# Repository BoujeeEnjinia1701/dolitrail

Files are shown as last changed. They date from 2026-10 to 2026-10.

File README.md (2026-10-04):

# DoliTrail

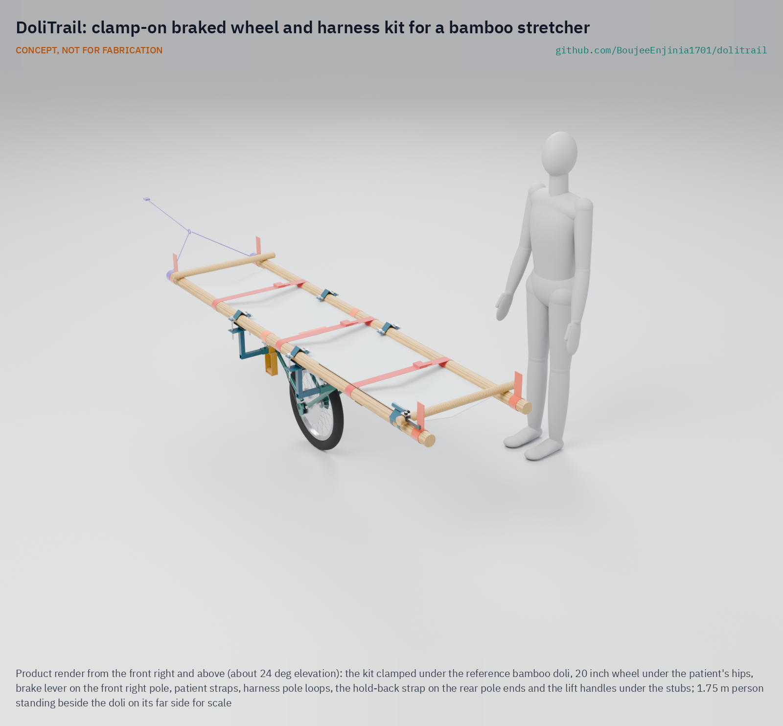
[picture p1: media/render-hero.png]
DoliTrail: clamp-on braked wheel and harness kit for a bamboo stretcher


     

**Area:** Autonomous and assisted mobility · **TRL:** 3 of 9 (proof of concept on paper; constructable design) · **Value-engineering target:** USD 1,500 (estimated cost USD 482) · **Difficulty:** 3 of 5

Adds a braked wheel and harness to the bamboo stretchers families use to carry patients to the road.

## Concept rationale

Villages without roads already have a way to move a patient: the doli, a stretcher made from bamboo poles and cloth, carried by relatives and neighbours. DoliTrail does not replace it. It adds a clamp-on wheel with a hand brake under the doli and a shoulder harness for the bearers. On level and gentle ground the wheel carries most of the weight and the bearers steer; on descents they hold speed with the brake lever; at steps, rocks and streams they lift the doli and carry it as they do today.

Keeping it as an add-on matters. Families build dolis from what is at hand, so a kit that clamps to poles of different sizes, costs little and can be carried to the village and fitted in minutes is more likely to be used than a new stretcher. The value-engineering target for the parts is USD 1,500 (the constructable design is estimated at USD 482), and the aim is a kit that a block health office or a village health committee can keep ready.

## Burning platform

The same scene repeats across India's hill and forest districts. In August 2026, ambulance staff in Mayurbhanj, Odisha, carried Sumitra Shundhi, in labour, about 7 km on a stretcher across rivers and streams because the 108 ambulance could not reach her village ([ANI, 2026](https://aninews.in/news/national/general-news/pregnant-woman-carried-7-km-on-stretcher-due-to-no-road-connectivity-in-odishas-mayurbhanj20260823102717/)). In Barwani, Madhya Pradesh, relatives carried a pregnant woman 8 km on a stretcher of cloth and bamboo sticks before an ambulance could take her a further 20 km to hospital ([The Tribune, 2021](https://www.tribuneindia.com/news/nation/madhya-pradesh-no-motorable-road-relatives-carry-pregnant-woman-on-makeshift-stretcher-for-8-km-287707)).

In Ri-Bhoi, Meghalaya, village volunteers took turns carrying a woman 36 weeks pregnant for nearly 5 km on a makeshift bamboo stretcher because no vehicle could reach the village ([The Tribune, 2022](https://www.tribuneindia.com/news/nation/pregnant-meghalaya-woman-taken-to-hospital-on-bamboo-stretcher-for-5-km-429099)). In Kondagaon, Chhattisgarh, hospital workers carried a woman 3 km on a hand-made dola over monsoon mud ([Gulf News, 2020](https://gulfnews.com/world/asia/india/india-video-of-a-pregnant-woman-who-was-taken-to-hospital-on-a-handmade-stretcher-has-gone-viral-1.1594298702634)). Each journey depends entirely on the strength of the people carrying.

## Where it could be used

### By industry

| Industry | Use |
| --- | --- |
| Public health and maternal care | Moving women in labour and patients from roadless villages to the ambulance point |
| Emergency medical services | Last-kilometre kit carried in ambulances that serve villages without roads |
| Disaster response | Casualty movement where roads are cut by floods or landslides |
| Mountain and trail rescue | Low-cost wheeled carry for volunteer teams on hill trails |
| Community health programmes | Kit held by village health committees and community health workers |

### By country or region

| Country or region | Why it matters there |
| --- | --- |
| India, Odisha | In August 2026 a woman in labour in Karanjia block, Mayurbhanj, was carried about 7 km across rivers and streams to reach an ambulance ([ANI, 2026](https://aninews.in/news/national/general-news/pregnant-woman-carried-7-km-on-stretcher-due-to-no-road-connectivity-in-odishas-mayurbhanj20260823102717/)). |
| India, Madhya Pradesh | In Barwani district, a forest village with no motorable road carried a pregnant woman 8 km on a cloth and bamboo stretcher ([The Tribune, 2021](https://www.tribuneindia.com/news/nation/madhya-pradesh-no-motorable-road-relatives-carry-pregnant-woman-on-makeshift-stretcher-for-8-km-287707)). |
| India, Meghalaya | Volunteers in Ri-Bhoi district carried a pregnant woman nearly 5 km on a bamboo stretcher over a road that had been in poor condition for years ([The Tribune, 2022](https://www.tribuneindia.com/news/nation/pregnant-meghalaya-woman-taken-to-hospital-on-bamboo-stretcher-for-5-km-429099)). |
| India, Chhattisgarh | In Kondagaon, monsoon mud cut the village off from vehicles and a woman was carried 3 km on a dola ([Gulf News, 2020](https://gulfnews.com/world/asia/india/india-video-of-a-pregnant-woman-who-was-taken-to-hospital-on-a-handmade-stretcher-has-gone-viral-1.1594298702634)). |
| India, Jammu and Kashmir | Army personnel carried a pregnant woman 6.5 km on a stretcher through heavy snow near the Line of Control in Boniyar ([The Tribune, 2022](https://www.tribuneindia.com/news/j-k/watch-army-men-carry-pregnant-woman-to-hospital-amid-heavy-snowfall-in-j-k-359452)). |

## What sparked the idea

On 23 August 2026, the 108 ambulance called for Sumitra Shundhi, in labour in Anlakanta village in Mayurbhanj, Odisha, could not reach her because there was no motorable road. The driver, the attendant and a helper carried her on the ambulance stretcher for about 7 km, crossing rivers and streams, until they reached the vehicle and took her to Karanjia hospital ([ANI, 2026](https://aninews.in/news/national/general-news/pregnant-woman-carried-7-km-on-stretcher-due-to-no-road-connectivity-in-odishas-mayurbhanj20260823102717/)). In many such villages the stretcher is a doli that families make themselves. DoliTrail asks how much of that 7 km a wheel and a brake could carry.

## Problem

In villages with no motorable road, families and health workers carry patients and women in labour for kilometres on hand-made bamboo stretchers to reach an ambulance. The whole weight rides on the bearers' shoulders, on steep, wet and uneven trails.

Full problem statement: [docs/01-problem.md](docs/01-problem.md)

## Concept

A clamp-on braked wheel and shoulder harness that fits the bamboo stretcher (doli) families already use; the bearers roll the patient along the trail, hold speed on descents with the brake lever, and lift it over steps.

Full design precis: [docs/02-concept.md](docs/02-concept.md) · Requirements: [docs/03-requirements.md](docs/03-requirements.md) · Calculations: [docs/04-calcs/01-sizing.md](docs/04-calcs/01-sizing.md) · Prototype build plan: [docs/05-build-plan.md](docs/05-build-plan.md) · Design decisions: [docs/06-design-decisions.md](docs/06-design-decisions.md)

## Key components

- Wheel and fork
- Pole clamps
- Cross frame and strap
- Brake and lever
- Bearer harnesses
- Patient straps
- Hold-back strap and lift handles
- Two carry bags and fitting card

## Building the prototype

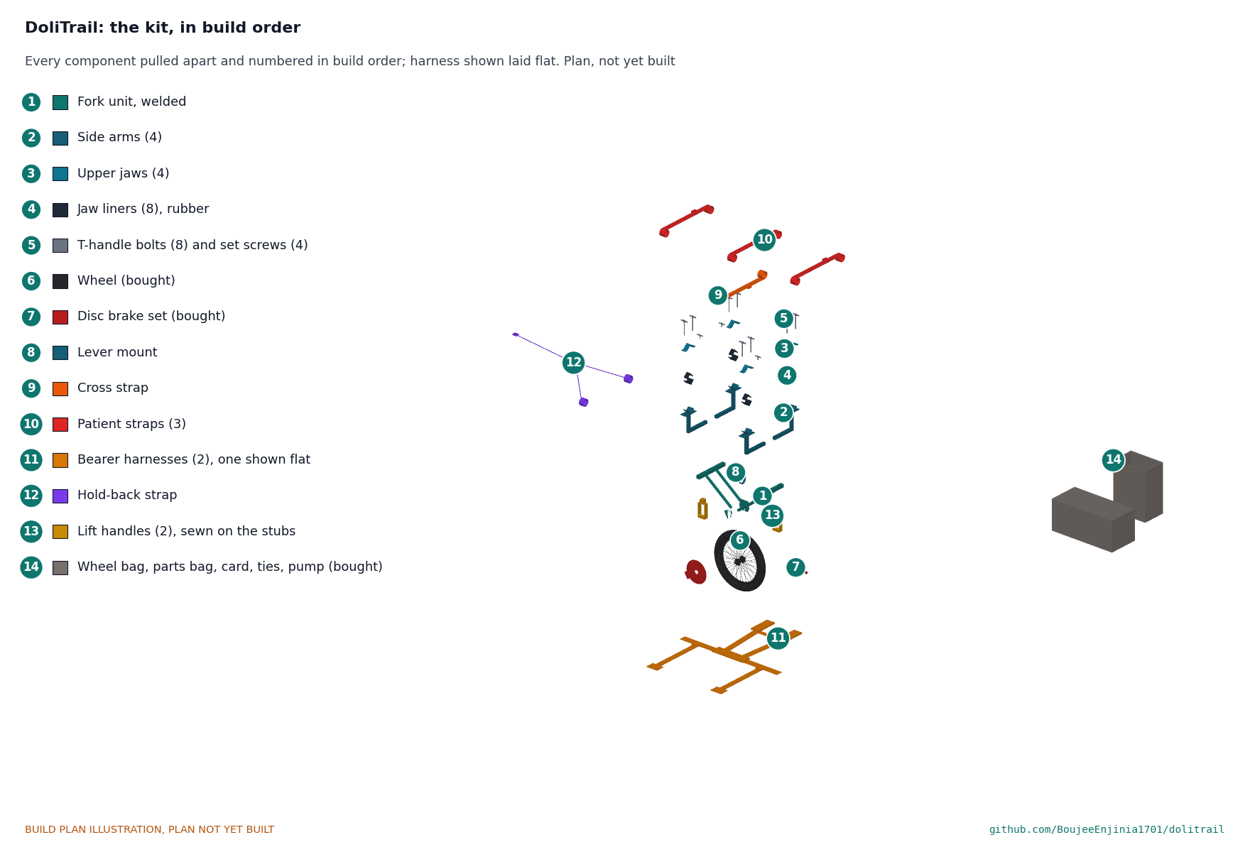
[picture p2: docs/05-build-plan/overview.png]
Every component, pulled apart and numbered in build order


The prototype build plan ([docs/05-build-plan.md](docs/05-build-plan.md)) shows how to make the kit and fit it to a doli, component by component, with a making sketch for every made part, close-ups of the joints and a picture for every assembly step. The steel parts are cut, bent, drilled and welded in a village workshop, the harnesses are sewn by a tailor, and the wheel and brake are ordinary bicycle parts. Fitting to a doli takes two people about five minutes and no tools. The plan is a plan, not yet built: the first kit carries sandbags until its proof loads and a wet ramp test have passed.

## Safety

> Safety-critical patient transport equipment. Published as an open engineering reference, never as certified medical or rescue equipment.
>
> Brake failure on a steep descent could lead to a runaway or a fall. Bearers keep hold of the poles at all times and lift and carry on slopes steeper than the tested limit.
>
> Lift and carry across streams and rivers; never roll the doli through moving water.
>
> Check clamps for grip on every fitting, since bamboo varies in size and can split.
>
> Straps must release quickly so the patient can be moved off the doli at once if needed.
>
> The doli rolls on one wheel and can tip sideways: bearers keep both hands on the poles. No person is carried until the frame, clamps and wheel have been proof-loaded (see the build plan, sections 5 and 6).
>
> This design is published as an open engineering reference. It is not certified equipment. CONCEPT, NOT FOR FABRICATION.

## Repository layout

| Folder | Contents |
| --- | --- |
| `docs/` | Problem, concept, requirements, calculations and design decisions |
| `cad/src/` | build123d Python source, the source of truth for all geometry |
| `cad/step/`, `cad/stl/` | Exported models for FreeCAD, other CAD tools and printing |
| `cad/drawings/` | 2D sketches and dimensioned drawings |
| `bom/` | Bill of materials |
| `electronics/` | KiCad schematics and PCB layouts |
| `firmware/` | Microcontroller code |
| `media/` | Renders, perspectives and photos |
| `build-log/` | Dated prototyping notes |

## Documentation

Controlled documents follow the portfolio [documentation standard](.kit/STANDARDS.md). Each carries a document ID (DLT-PRC-001 for the precis), a version and a revision history. Branded PDFs are built with `python .kit/render.py` and attached to GitHub Releases when a document is tagged, for example `DLT-PRC-001/v1.0`.

## Credits

Designed by Amish Chadha at Design Molecule Labs. See [CONTRIBUTORS.md](CONTRIBUTORS.md) for roles. To cite this design, use [CITATION.cff](CITATION.cff) (GitHub shows it as "Cite this repository").

AI assistance (Claude) was used to accelerate prototype documentation and first-pass research. Design direction and all decisions are Amish Chadha's, recorded in this repository's decision records (`docs/decisions/`).

## Licenses

- **Hardware** (CAD, drawings, BOM, electronics): [CERN-OHL-S v2](LICENSE)
- **Software** (firmware, scripts, notebooks): [MIT](LICENSE-SOFTWARE)

A project of the [Design Molecule](https://designmolecule.com) lab.

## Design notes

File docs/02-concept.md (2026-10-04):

---
doc_id: DLT-PRC-001
title: DoliTrail design precis
project: DoliTrail
doc_type: Precis
version: "0.3"
status: Draft
date: '2026-10-03'
author: Amish Chadha
license: CERN-OHL-S-2.0
revisions:
- version: "0.1"
  date: '2026-09-30'
  author: Amish Chadha
  change: Initial scaffold
- version: "0.2"
  date: '2026-10-03'
  author: Amish Chadha
  change: TRL 2 and 3 update; constructable kit (DLT-DDR-001, DLT-DDR-002), components with BOM numbers, first-order numbers, safety
- version: "0.3"
  date: '2026-10-03'
  author: Amish Chadha
  change: "Amish's round-2 decisions 6A to 9A (DLT-DDR-003): wheel proof load, hold-back strap and carry rule, two bags, lift handles and four lifters at steps"
---

# DoliTrail design precis

Adds a braked wheel and harness to the bamboo stretchers families use to carry patients to the road.

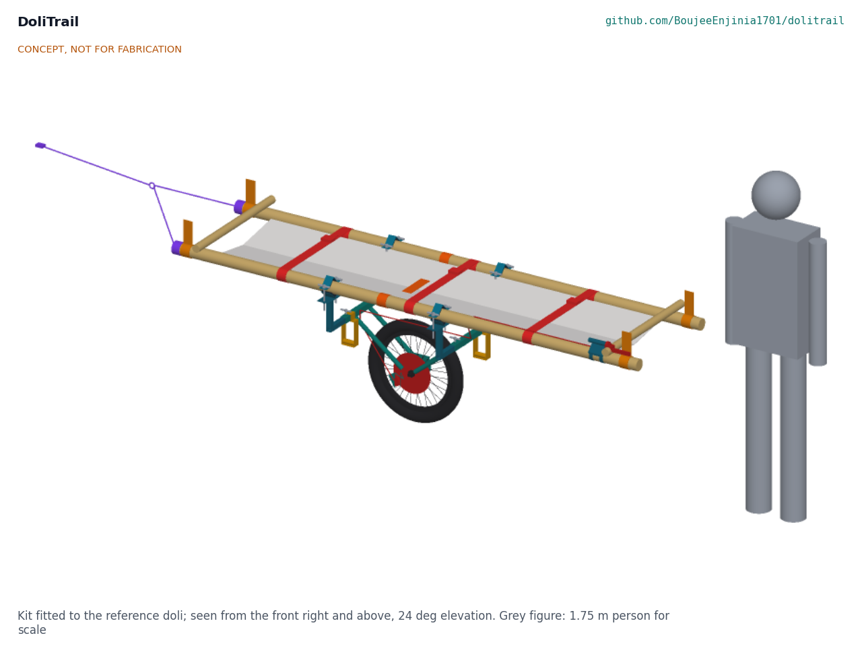
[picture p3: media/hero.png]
DoliTrail fitted to the reference doli


*Figure 1. The kit fitted to the reference doli, with a 1.75 m person for scale (concept render).*

## How it works

DoliTrail is a clamp-on kit for the doli a family has already built. A single 20 inch wheel runs under the patient's hips in a welded steel fork unit. Four side arms slide into the fork unit's two cross stubs, set to the doli's pole spacing, and each ends in a rubber-lined steel V that the bamboo pole sits in; an upper jaw and two T-handle bolts close each clamp by hand. A cross strap round both poles above the wheel keeps the bed from sagging onto the tyre. A disc brake on the wheel is worked by a lever with a parking lock, strapped to the front right pole beside the front bearer's hand. Each bearer wears a harness whose slings take the pole ends at knuckle height, so on level ground and gentle slopes the wheel carries most of the weight and the bearers balance and steer. On descents the front bearer holds speed with the brake, and the rear (uphill) bearer is tied to the rear pole ends by a hold-back strap from the hip belt; on wet clay steeper than 20 per cent the bearers lift and carry. At steps of more than about 250 mm four people lift: the two bearers and two helpers at webbing lift handles on the cross stubs. At rocks and streams the bearers lift the doli and carry it, as they do today. The kit walks in with the two bearers in two bags, and each bought wheel is proof-loaded to 285 kg before the kit is used.

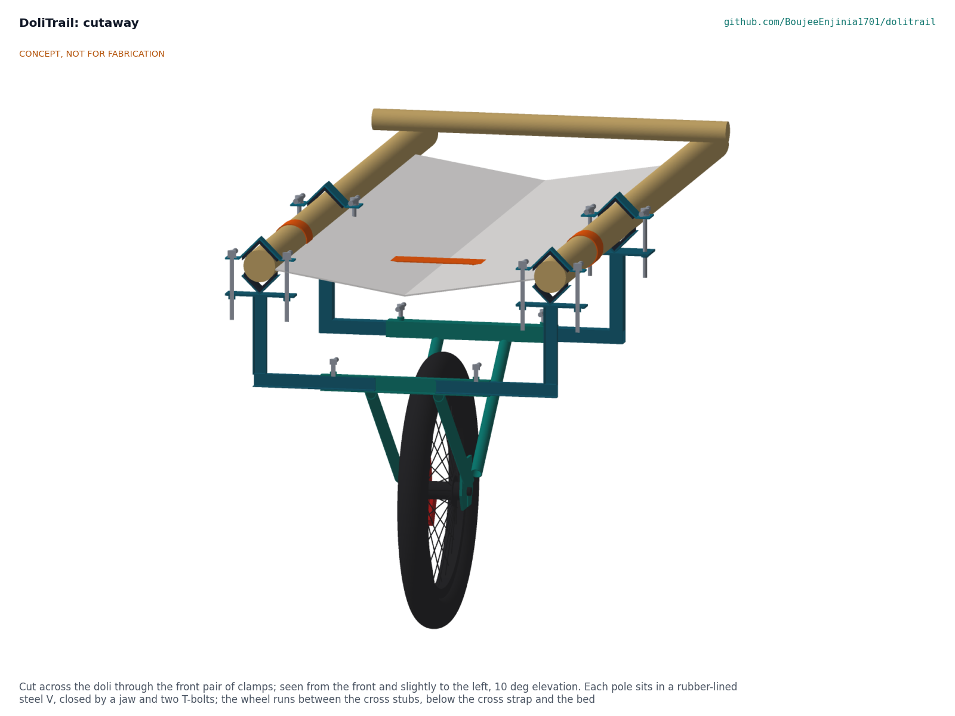
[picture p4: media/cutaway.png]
Cut across the doli through the front clamps


*Figure 2. Cut across the doli through the front pair of clamps.*

## Components

*Table 1. Components (numbers are BOM lines in `bom/bom.csv`).*

| # | Component | Role |
| --- | --- | --- |
| 1 | Fork unit | Welded steel: two 30 mm square cross stubs, four 22 mm struts, dropout plates with the brake caliper lobe |
| 2 | Side arms (4) | Square tube spigot that slides in a stub, a post and a 90 deg V saddle under the pole |
| 3 | Upper jaws (4) | Bent 3 mm steel V over the pole, with two ears for the bolts |
| 4 | Jaw liners (8) | 5 mm rubber in each saddle and jaw: grip on wet bamboo and no crushing points |
| 5 | T-handle bolts (8) and set screws (4) | Close the clamps and lock the arms by hand; no loose tools |
| 6 | Wheel | 20 inch cargo or tricycle wheel, 57-406 knobbly tyre, disc hub, solid axle |
| 7 | Disc brake set | 203 mm rotor, cable caliper with sintered pads, lever with parking lock, cable |
| 8 | Lever mount | Rubber-lined V with a 22.2 mm bar stub, strapped to the front right pole |
| 9 | Cross strap | 50 mm webbing loop round both poles above the wheel, under the bed |
| 10 | Patient straps (3) | Chest, hips and legs; cam buckles with a pull tab |
| 11 | Bearer harnesses (2) | Hip belt, padded shoulder yoke and two adjustable slings ending in pole loops |
| 12 to 15 | Wheel bag, fitting card, cable ties, pump and puncture kit | Carry, fit and keep the kit running |
| 16 | Hold-back strap | Webbing end caps over the rear pole ends, legs to a ring and a tail to the rear bearer's hip belt (decision 7A) |
| 17 | Lift handles (2) | Webbing loops sewn round the cross stubs for two helpers at steps (decision 9A) |
| 18 | Parts bag | Second bag, so each bearer carries one bag (decision 8A) |

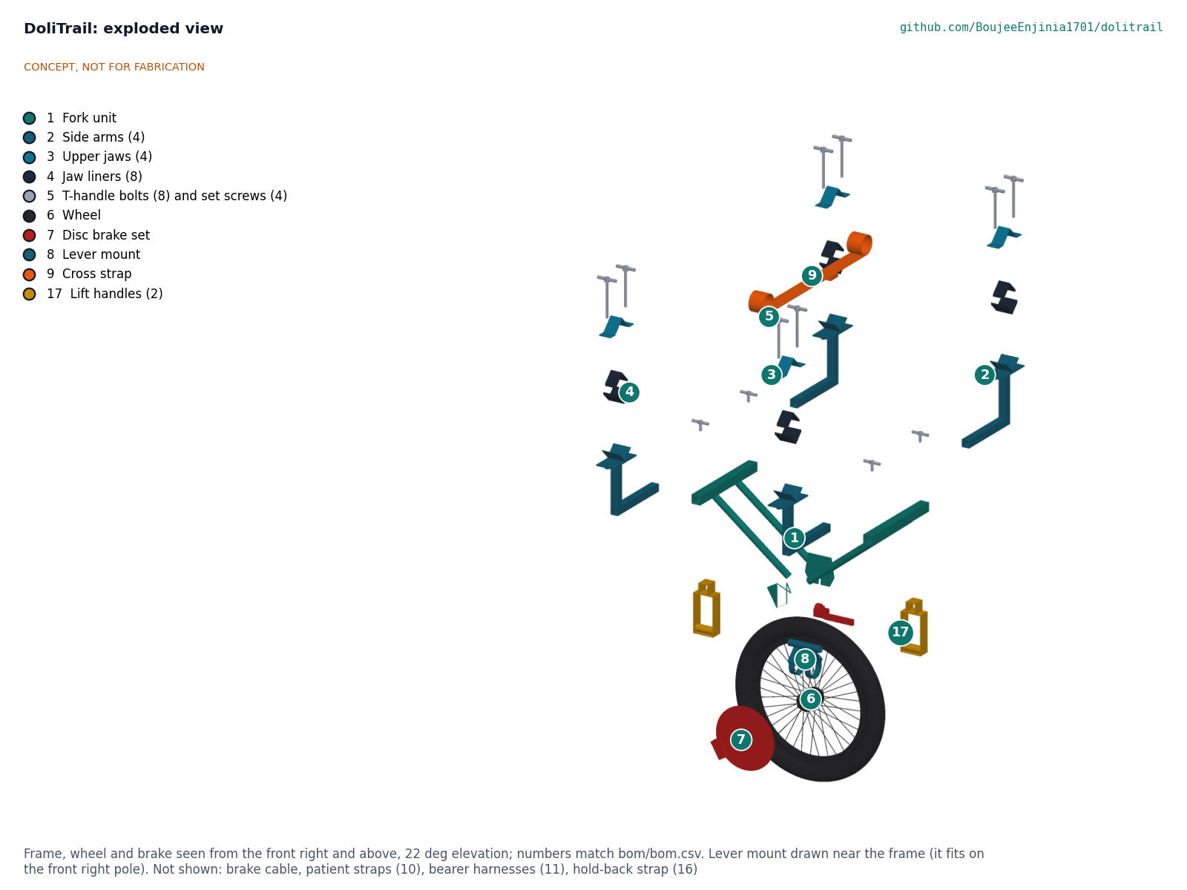
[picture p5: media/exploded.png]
Exploded view


*Figure 3. Exploded view of the frame, wheel and brake; numbers match the BOM.*

## Key design choices

- **One wheel under the hips** (DLT-DDR-001, D1). The wheel stays inside the doli's own width; a pair would need a track wider than most trails.
- **Clamp on, adjust by hand** (D2, DLT-DDR-002). Telescoping arms reach poles 450 to 600 mm apart; V saddles self-centre poles of 40 to 80 mm; T-handles mean no spanner is needed.
- **Disc brake with a parking lock** (D3). Works when wet better than a rim brake on a muddy rim; the lock holds the doli when the bearers rest on a slope.
- **Slings, not cups** (D4). A webbing pole loop fits any pole end; the scaffold's "pole-end cups" became loops.
- **Ordinary parts.** Bicycle and cycle-rickshaw parts, mild steel tube a village workshop can weld, webbing a tailor can sew.

## First-order numbers

All from DLT-CAL-001; estimates are marked.

*Table 2. Key figures.*

| Quantity | Value |
| --- | --- |
| Rolling weight: 120 kg patient, 10 kg doli, 12.5 kg fitted kit | 142.5 kg |
| Load per bearer on a level trail (estimate) | about 14 kg, against 65 kg carried by two bearers (79 per cent less) |
| Front bearer on a 30 per cent descent, brake on (estimate) | about 46 kg |
| Brake torque factor on a 30 per cent grade, wet | 1.23 |
| Tyre grip factor on a 30 per cent grade: wet ramp; wet clay | 1.44; 0.84 (lift and carry on wet clay over 20 per cent, where it is 1.37) |
| Clamp slip resistance, one pole, wet | 3.96 kN (factor 2.6 on 1.5 kN) |
| Lowest structural factor on yield at twice the rated load | 2.01 (struts); each wheel proof-loaded to 285 kg |
| Width on the reference doli | 680 mm |
| Kit in two bags; fitted | 7.2 kg and 8.3 kg; 12.5 kg |
| Lift at a 400 mm step, four people | about 36 kg each |
| Fitting time, two people (estimate) | about 4.7 min |
| Estimated parts cost | USD 482 (value-engineering target USD 1,500) |

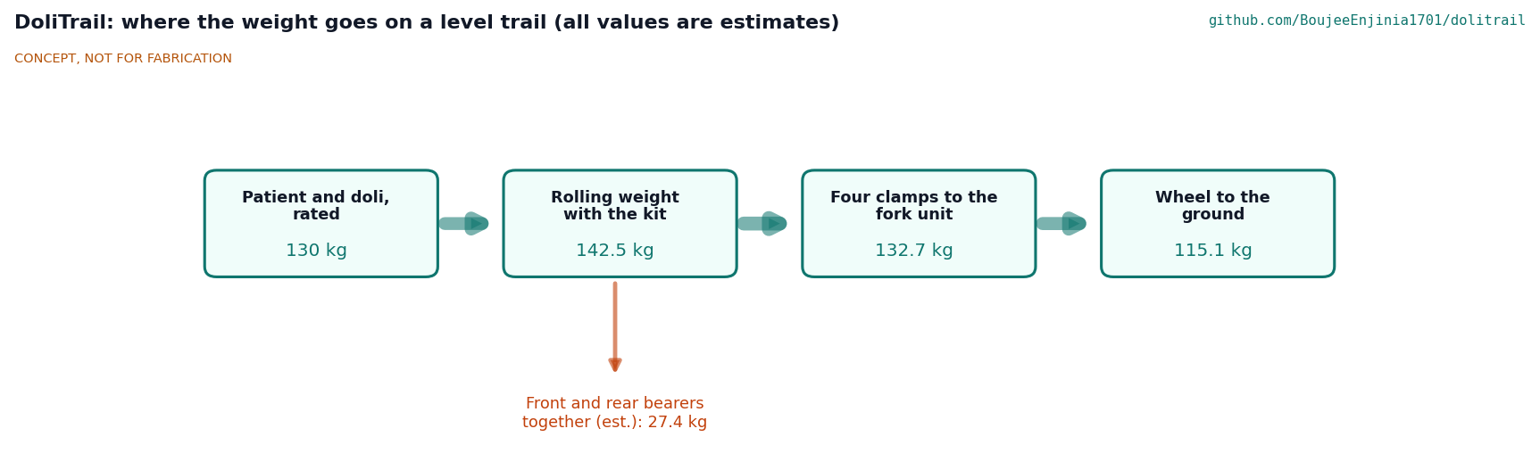
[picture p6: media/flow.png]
Where the weight goes


*Figure 4. Where the weight goes on a level trail (estimates).*

## Patent design-arounds

From the preliminary patent, trademark and prior-art screen (not legal advice), kept unchanged:

- Use DoliTrail's own clamp geometry and colours, distinct from the CMC or Ferno Mule II litter wheel. The DoliTrail clamp is a rubber-lined 90 deg V with a separate jaw and two hand bolts, on telescoping square arms; the colours are teal and blue.
- Confirm that US7922183B2 (Hill-Rom stretcher brake) has lapsed for non-payment of fees before using a similar brake arrangement. DoliTrail uses an ordinary bicycle disc brake on the wheel hub, not a stretcher-mounted brake; the check is still listed in DLT-DEC-001.

## Shared blocks

- CalRig proof-load for clamp, fork, wheel and harness load tests (TRL 4).

## Safety

> **Safety:** Safety-critical patient transport equipment. Published as an open engineering reference, never as certified medical or rescue equipment.
>
> Brake failure or tyre slip on a steep wet descent could lead to a runaway or a fall. Bearers keep hold of the poles at all times, and lift and carry on wet slopes steeper than the tested limit.
>
> The doli rolls on one wheel and can tip sideways. Both bearers steady it with both hands; on a 15 per cent side slope each hand holds about 16 kg up or down.
>
> Lift and carry across streams and rivers; never roll the doli through moving water.
>
> Check every clamp for grip on every fitting, since bamboo varies in size and can split. Tighten by hand only.
>
> Patient straps must release with one pull so the patient can be moved off the doli at once.
>
> No patient is carried until the frame, clamps and wheel have been proof-loaded (DLT-BLD-001, sections 5 and 6).

This design is published as an open engineering reference. It is not certified equipment.

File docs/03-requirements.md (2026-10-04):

---
doc_id: DLT-REQ-001
title: DoliTrail requirements
project: DoliTrail
doc_type: Requirements
version: "0.4"
status: Draft
date: '2026-10-04'
author: Amish Chadha
license: CERN-OHL-S-2.0
revisions:
- version: "0.1"
  date: '2026-09-30'
  author: Amish Chadha
  change: Initial scaffold
- version: "0.2"
  date: '2026-10-03'
  author: Amish Chadha
  change: TRL 3 status from DLT-CAL-001 on the constructable design; R10 and R11 added (DLT-DDR-001); targets R1 to R9 unchanged
- version: "0.3"
  date: '2026-10-03'
  author: Amish Chadha
  change: "Status of R3, R5, R7, R8 and R9 after Amish's round-2 decisions 6A to 9A (DLT-DDR-003); targets unchanged; wording of R7 and R8 posed to Amish (DLT-DEC-001, O5)"
- version: "0.4"
  date: '2026-10-04'
  author: Amish Chadha
  change: "R7 and R8 restated by Amish's round-3 decision 1A (DLT-DDR-004): R7 as two bags of 10 kg or less, one per bearer; R8 as four people at steps, two at the lift handles; both met as designed"
---

# DoliTrail requirements

Requirements for the kit fitted to the reference doli (two 60 mm bamboo poles, 2.55 m long, at 550 mm centres) carrying the rated patient. R1 to R9 keep the targets set at TRL 1; R10 and R11 were added at TRL 2 (DLT-DDR-001). Status is the paper result at TRL 3 from DLT-CAL-001; every requirement is verified by test at TRL 4. Requirements not met or at risk are posed to Amish as decisions in `docs/REVIEW.md` and `docs/06-design-decisions.md`.

On 2026-10-03 Amish decided the four requirement decisions on R3, R5, R7 and R8 as recommended: "i agree with all the 46 recommendations you provided. please proceed." (decisions 6A to 9A, DLT-DDR-003). The targets are unchanged. R7 and R8 are met only in the way those decisions set out (two bags; four people at steps). On 2026-10-04 Amish decided option 1A on their wording: "For round 3, I agree with all your proposed recommendations". R7 is now restated as "two bags of 10 kg or less, one per bearer" and R8 as "four people at steps, two at the lift handles" (DLT-DDR-004). Both are met as designed.

*Table 1. Requirements.*

| ID | Requirement | Target | Verification (TRL 3 or later) | TRL 3 status |
| --- | --- | --- | --- | --- |
| R1 | Fits real dolis | Clamps grip poles of 40 to 80 mm diameter and hold without slipping under a 1.5 kN load (target) | Fit trials on 10 field-made dolis and CalRig pull tests | Met on paper: the clamps close on 40 and 80 mm poles in the model; two clamps on one pole resist 3.96 kN wet (factor 2.6); bamboo crushing factor 2.0 to confirm on real poles |
| R2 | Quick to fit | Two people fit the kit to a doli in under 5 minutes | Timed trials using only the fitting card | Met on paper (estimate): about 4.7 min, with the wheel carried fitted in the fork unit |
| R3 | Carry load | Rated for a 120 kg (265 lb) patient plus doli, with a 2 to 1 safety margin on the wheel, fork and clamps | CalRig proof-load test | Met on paper for the fork, arms and clamps (lowest factor 2.01 on yield at twice the rated load). The wheel and tyre are not catalogue-rated for twice the wheel load, so each bought wheel is proof-loaded to 285 kg before use, with the heavier tricycle wheel if it fails (decision 6A) |
| R4 | Reduce bearer load | Average vertical load per bearer reduced by at least 60 per cent on level trail compared with carrying | Load cells in the harness cups during trail trials | Met on paper (estimate): 79 per cent (about 14 kg per bearer against 65 kg) |
| R5 | Brake holds on descents | Holds the rated load stationary on a 30 per cent grade, wet | Wet ramp test | Met on paper on the wet test ramp: brake factor 1.23, tyre grip factor 1.44. On wet clay the grip factor on 30 per cent is 0.84, so the bearers lift and carry on wet clay steeper than 20 per cent (grip factor 1.37 there), and a hold-back strap ties the uphill bearer to the rear pole ends (decision 7A) |
| R6 | Narrow trails | Overall width with wheel at or below 700 mm (28 in) | Measure; walk a marked 0.8 m trail course | Met on the reference doli: 680 mm; any doli with poles at more than 570 mm centres is wider than 700 mm by itself |
| R7 | Portable | Two bags of 10 kg (22 lb) or less, one per bearer | Weigh; timed carry of the bagged kit | Met as designed (decisions 8A and 1A): two bags of 7.2 and 8.3 kg, one carried by each bearer; the whole kit is 15.5 kg |
| R8 | Lift over obstacles | Four people at steps, two at the lift handles: the fitted doli goes over a 400 mm step without removing the wheel | Obstacle course trial | Met as designed (decisions 9A and 1A): the two bearers and two helpers at lift handles on the cross stubs, about 36 kg each. Two bearers alone would each lift about 71 kg to chest height, so the drill rules that out |
| R9 | Low cost | Parts cost at or below $1,500 USD for the kit | Costed bill of materials | Value-engineering target: USD 1,500. Estimated cost of the constructable design: USD 482 (USD 1,018 under the target) |
| R10 | Patient release | Each patient strap frees with one pull of one hand in 3 s or less | Timed trial, gloved hand | Met by design: cam buckles with a pull tab |
| R11 | Brake within reach | The front bearer works the brake and its parking lock without letting go of the poles | Trial with bearers of 1.5 to 1.8 m | Met on paper: lever on the front right pole about 100 to 150 mm behind the pole loop |

## Assumptions

- Rated load: a 120 kg patient on a 10 kg doli; with the 12.5 kg fitted kit the rolling weight is 142.5 kg (DLT-CAL-001, A1).
- The wheel is placed under the patient's hips to within 100 mm; bearers steady the doli with about 5 per cent of the rolling weight each.
- Typical routes roll on level ground and moderate grades; bearers lift and carry at rocks, water and wet clay steeper than 20 per cent, and four people lift at steps (decisions 7A and 9A).
- Bamboo poles carry the patient through four clamps at about 600 mm spacing near mid-span.
- Ambulance services and health committees would keep and maintain kits.

> **Safety:** These requirements describe equipment that carries a person over dangerous ground. A paper result is not a test. No patient is carried until the TRL 4 proof loads and first checks in DLT-BLD-001 pass.

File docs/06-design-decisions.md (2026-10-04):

---
doc_id: DLT-DEC-001
title: DoliTrail design decisions register
project: DoliTrail
doc_type: Design decisions register
version: "0.3"
status: Draft
date: '2026-10-04'
author: Amish Chadha
license: CERN-OHL-S-2.0
revisions:
- version: "0.1"
  date: '2026-10-03'
  author: Amish Chadha
  change: Register opened; design decisions made under Amish's 2026-10-03 pre-approvals; four requirement decisions proposed, awaiting Amish
- version: "0.2"
  date: '2026-10-03'
  author: Amish Chadha
  change: "O1 to O4 decided by Amish (6A to 9A, DLT-DDR-003) and moved to Decisions made; new O5 on the wording of R7 and R8, proposed, awaiting Amish"
- version: "0.3"
  date: '2026-10-04'
  author: Amish Chadha
  change: "O5 decided by Amish (round-3 decision 1A, DLT-DDR-004) and moved to Decisions made; no open decisions"
---

# DoliTrail design decisions register

Every design decision still to be made, and every decision made, in one place. Each decision is argued in full in its decision record under `docs/decisions/` or in `docs/REVIEW.md`; this register is the index Amish works from. The build plan (`docs/05-build-plan.md`) describes the design as it stands and does not list decisions.

> **Safety:** Several entries set safety limits (one wheel steadied with both hands, a parking lock on every kit, a solid axle, hand-tight clamps, sandbags before people, lift and carry on wet clay). Each takes the conservative option and names the evidence that would relax it. DoliTrail is not certified medical or rescue equipment.

## Open decisions

None. O1 to O4 were decided on 2026-10-03 and O5 (the wording of R7 and R8) on 2026-10-04; all are under Decisions made.

## To confirm when parts are bought

These are facts that can only be settled with real parts, real dolis or the first partner. None changes a decision; each may change a size or a limit.

*Table 2. Items to confirm.*

| # | What to confirm | Why it matters | Source |
| --- | --- | --- | --- |
| 1 | Seller's ratings of the bought wheel (200 kg assumed) and tyre (150 kg); each wheel is proof-loaded to 285 kg before use (decision 6A) | R3 | DLT-CAL-001, A10 |
| 2 | Brake clamp force at about 150 N hand pull with the lock set (2.0 kN per pad assumed) and wet pad friction (0.35) | R5 brake factor | DLT-CAL-001, A5 |
| 3 | Diametral crushing of local bamboo poles of 40 to 80 mm in the V jaws (4.0 kN for 40 mm length assumed) | R1 crushing factor, the hand-tight rule | DLT-CAL-001, A7 |
| 4 | Rubber on wet bamboo friction (0.35 assumed) | R1 slip factor | DLT-CAL-001, A6 |
| 5 | Tyre grip on the partner's trails, wet (0.35 assumed), and whether the 20 per cent carry limit on wet clay suits them | R5, decision 7A | DLT-CAL-001, A4, A13 |
| 6 | How real dolis' beds are fixed to the poles; whether the lashing can be slid aside at the clamp points, and what to do with sewn sleeves | Clamp position; fitting time | DLT-DDR-002, A3 |
| 7 | Pole spacing, diameter and length of dolis in the partner's villages | Arm range and width (R6) | DLT-DDR-001, D6 |
| 8 | Masses of the bought wheel, brake, harness webbing and bag | R7 | DLT-CAL-001, A12 |
| 9 | That US7922183B2 (Hill-Rom stretcher brake) has lapsed, before any public claim about the brake | Design-around | DLT-PRC-001 |
| 10 | Breaking strength of the 25 and 50 mm webbing bought for the hold-back strap and lift handles (5 and 10 kN assumed), and that the end caps stay on poles of 40 to 80 mm under a backward pull | Decisions 7A and 9A | DLT-CAL-001, A14 |

## Value engineering

Value-engineering target: USD 1,500 (a hypothetical control target, not a limit). Estimated cost of the constructable design: USD 482 (USD 1,018 under the target). Main cost drivers and savings worth trying:

- The largest lines are the two harnesses (USD 70), the fork unit (USD 62), the four side arms (USD 60), the wheel (USD 55) and the brake set (USD 45).
- Savings worth trying: cycle-rickshaw workshops already weld similar frames and could make the fork unit and arms together in a batch (perhaps USD 30 a kit); harnesses from used truck seat-belt webbing (about USD 25); a secondhand cargo wheel inspected and proof-loaded (about USD 25).
- Decisions 6A to 9A added USD 27 (hold-back strap USD 6, two lift handles USD 6, parts bag USD 15). If a bought wheel fails its proof load, the heavier tricycle wheel adds about USD 30.

## Decisions made

*Table 3. Decisions made.*

| Date | Decision | Decided by | Record |
| --- | --- | --- | --- |
| 2026-10-03 | TRL 2 review items D1 to D9: one wheel under the hips; rubber-lined V clamps on telescoping arms with hand bolts; cable disc brake with a parking lock on every kit; pole loops on slings; 20 inch cargo wheel with a solid axle; rated patient 120 kg on a 10 kg reference doli; first-trial kits kept in the ambulance; first co-design candidates (a district 108 ambulance operator in Mayurbhanj, a maternal health NGO in the same block, a volunteer mountain rescue group; none approached yet); R10 and R11 added, R1 to R9 targets unchanged; pitch, design-arounds and budget unchanged | Amish, pre-approval of 2026-10-03: "start with the first 14 repos from the list of 29 projects. I pre-approve the batch runs along with any recommendations you come up with. I also accept any cost overruns or variations from the assumed scope cost." and "Proceed with the remaining 15 scaffolds" | DLT-DDR-001 |
| 2026-10-03 | Design for construction, changes C1 to C11: welded fork unit with cross stubs and struts; telescoping side arms with V saddles; T-handle bolts and set screws; cross strap; caliper lobe on the dropout plate; lever mount; pole loops; solid axle in open slots; clamps on bare pole; wheel bag; pump and ties | Amish, same pre-approvals | DLT-DDR-002 |
| 2026-10-03 | Assumptions A1 to A5: sound poles only; clamps hand tight, never with a bar (conservative; relaxed only by crush tests on local bamboo); sewn bed sleeves not fitted until the partner trial decides; bought ratings confirmed; jig-welded, inspected frame | Amish, same pre-approvals | DLT-DDR-002 |
| 2026-10-03 | Sandbags before people: no person on the doli before the frame and wheel proof loads and the wet ramp test pass; the first person carried is a healthy volunteer (conservative; a gate, not relaxed) | Amish, same pre-approvals | DLT-BLD-001, sections 5 and 6 |
| 2026-10-03 | O1, R3 (6A): keep the 20 inch cargo wheel; proof-load each bought wheel to 285 kg before use; heavier tricycle wheel and 20 x 2.4 cargo tyre only if it fails | Amish: "i agree with all the 46 recommendations you provided. please proceed." | DLT-DDR-003 |
| 2026-10-03 | O2, R5 (7A): hold-back strap from the uphill bearer's hip belt to the rear pole ends; lift and carry on wet clay steeper than 20 per cent | Amish, same words | DLT-DDR-003 |
| 2026-10-03 | O3, R7 (8A): the kit in two bags, about 7 and 8 kg, one per bearer | Amish, same words | DLT-DDR-003 |
| 2026-10-03 | O4, R8 (9A): four people lift at steps, two at lift handles added to the frame, about 36 kg each | Amish, same words | DLT-DDR-003 |
| 2026-10-03 | Appearance model departures: bamboo and cloth colours for the family's doli, a 1.75 m mannequin standing beside the doli on its far side, and a repeated front right clamp for the detail view, drawn for the renders only | Amish, same pre-approvals | docs/REVIEW.md, TRL 3 section |
| 2026-10-04 | O5, R7 and R8 (1A): R7 restated as "two bags of 10 kg or less, one per bearer"; R8 restated as "four people at steps, two at the lift handles"; both met as designed | Amish: "For round 3, I agree with all your proposed recommendations" | DLT-DDR-004 |

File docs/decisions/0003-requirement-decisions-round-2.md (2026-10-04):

---
doc_id: DLT-DDR-003
title: DoliTrail requirement decisions on R3, R5, R7 and R8
project: DoliTrail
doc_type: Design decision record
version: "0.1"
status: Draft
date: '2026-10-03'
author: Amish Chadha
license: CERN-OHL-S-2.0
revisions:
- version: "0.1"
  date: '2026-10-03'
  author: Amish Chadha
  change: Amish's round-2 decisions 6A, 7A, 8A and 9A recorded and carried into the design
---

# 0003: Requirement decisions on R3, R5, R7 and R8

- **Date:** 2026-10-03
- **Status:** accepted. Decided by Amish on 2026-10-03: "i agree with all the 46 recommendations you provided. please proceed." For DoliTrail this accepts the recommendations on open decisions O1 to O4 of DLT-DEC-001 (portfolio items 6A, 7A, 8A and 9A).

## Context

The TRL 3 calculations (DLT-CAL-001 v0.1) left four requirements short or at risk: the wheel and tyre are not catalogue-rated for twice the wheel load (R3); on wet clay the tyre slides before the brake slips (R5); the kit weighed 14.8 kg in one bag (R7); and two bearers would each lift about 71 kg to chest height to clear a 400 mm step (R8). Each was posed with options in `docs/REVIEW.md` (D-A1 to D-A4).

## Options considered

The options are set out in full in `docs/REVIEW.md`, TRL 3 section, "Decisions for Amish". In short: R3 by proof load, a heavier tricycle wheel or a scooter wheel; R5 by a hold-back strap and a carry rule, a drag claw or a mud tyre; R7 by two bags, lighter parts or an aluminium frame; R8 by four lifters with handles or shoulder yokes.

## Decision

| Item | Requirement | Decision (option A in each case) |
| --- | --- | --- |
| 6A | R3 | Keep the 20 inch cargo wheel. Proof-load each bought wheel, with its tyre at full pressure, to 285 kg for 10 minutes before the kit is used; move to the heavier 20 inch tricycle wheel and 20 x 2.4 cargo tyre only if it fails. |
| 7A | R5 | Add a hold-back strap from the uphill (rear) bearer's hip belt to the rear pole ends, and the rule to lift and carry on wet clay steeper than 20 per cent. |
| 8A | R7 | Split the kit into two bags, one carried by each bearer: about 7 and 8 kg. |
| 9A | R8 | Four people lift at steps: the two bearers at the pole ends and two helpers at two lift handles added to the frame, about 36 kg each. |

## Consequences

Carried out on 2026-10-03:

- **Model** (`cad/src/model.py`): hold-back strap (BOM line 16): two closed webbing end caps 40 mm deep over the rear pole ends, so the pull bears on the end of each pole, two 25 mm legs to a 40 mm steel ring and a 600 mm tail with a cam buckle to the rear bearer's hip belt. Lift handles (line 17): a 40 mm webbing band sewn shut round each cross stub, 100 mm off centre (front stub left, rear stub right, so the helpers stand on opposite sides), with a 130 mm hand loop and a foam grip. Sixteen new constructability checks (91 of 91 pass): caps on the pole ends and 5 mm clear of the harness loops; legs, ring and tail clear of the poles, cross sticks and harness loops; handles on their stubs, clear of the arms, set screws and brake, 69 mm clear of the tyre, 162 mm of hand room under the poles and bed, 358 mm above the ground.
- **Bags:** the wheel bag (line 12) carries the fork unit with the wheel, brake, lift handles and pump kit (7.2 kg); a new parts bag (line 18) carries the arms, jaws, bolts, lever mount, straps, harnesses and hold-back strap (8.3 kg).
- **Results** (DLT-CAL-001 v0.2): R3 frame factor 2.01, wheel proof load 285 kg [S12]; R5 brake 1.23, wet ramp grip 1.44, wet clay grip 1.37 at the 20 per cent carry limit [B9], hold-back pull 65 N on 30 per cent wet clay met by surprise [B10]; R7 two bags of 7.2 and 8.3 kg [K13], [K14], 15.5 kg in all; R8 about 36 kg each with four people [H4], 350 N on each handle [H5].
- **Cost and mass:** USD 27 more (hold-back strap USD 6, two lift handles USD 6, parts bag USD 15). Value-engineering target: USD 1,500. Estimated cost of the constructable design: USD 482 (USD 1,018 under the target). Fitted kit 12.5 kg; rolling weight 142.5 kg.
- **New question:** R7 and R8 are met only in the way these decisions set out (per bag; with four people), while their wording still says one person and two bearers. Whether to restate them is posed to Amish as O5 in DLT-DEC-001.

> **Safety:** The hold-back strap helps, it does not replace the carry rule: on wet clay steeper than 20 per cent the bearers lift and carry. The wheel proof load is done with sandbags under safety stop S3 before any person is carried.

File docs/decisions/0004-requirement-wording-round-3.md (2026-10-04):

---
doc_id: DLT-DDR-004
title: DoliTrail wording of R7 and R8
project: DoliTrail
doc_type: Design decision record
version: "0.1"
status: Draft
date: '2026-10-04'
author: Amish Chadha
license: CERN-OHL-S-2.0
revisions:
- version: "0.1"
  date: '2026-10-04'
  author: Amish Chadha
  change: Amish's round-3 decision 1A recorded; R7 and R8 restated
---

# 0004: Wording of R7 and R8

- **Date:** 2026-10-04
- **Status:** accepted. Decided by Amish on 2026-10-04: "For round 3, I agree with all your proposed recommendations". For DoliTrail this accepts option A of open decision O5 in DLT-DEC-001 (portfolio item 1A).

## Context

Decisions 8A and 9A (DLT-DDR-003) met R7 and R8 with two bags and four people, while the requirement text still said one person carries the kit and two bearers lift at steps.

## Options considered

A: restate R7 and R8 to match the design. B: keep the wording and report both as met only per bag and with four people. Recommendation was A.

## Decision

- R7 is restated as "two bags of 10 kg or less, one per bearer". Result: bags of 7.2 and 8.3 kg. Met as designed.
- R8 is restated as "four people at steps, two at the lift handles". Result: about 36 kg each. Met as designed.

## Consequences

Requirements text, calculation note wording and registers only. No geometry, bill of materials or cost change. Value-engineering target: USD 1,500. Estimated cost of the constructable design: USD 482 (USD 1,018 under the target).

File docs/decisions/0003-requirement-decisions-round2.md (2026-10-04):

---
doc_id: DLT-DDR-003
title: DoliTrail requirement decisions, round 2
project: DoliTrail
doc_type: Design decision record
version: "0.1"
status: Draft
date: '2026-10-03'
author: Amish Chadha
license: CERN-OHL-S-2.0
revisions:
- version: "0.1"
  date: '2026-10-03'
  author: Amish Chadha
  change: Decisions O1 to O4 on R3, R5, R7 and R8, decided by Amish on 2026-10-03 and carried into the model, calculations, BOM and build plan
---

# 0003: Requirement decisions, round 2

- **Date:** 2026-10-03
- **Status:** Decided. Decided by Amish Chadha, 2026-10-03: "i approve all of the 47 recommendations provided by you. Execute them." Each decision below is the recommendation as worded in `docs/06-design-decisions.md` (DLT-DEC-001 v0.1), including its conditions.

> **Safety:** Three of these decisions (O1, O2 and O4) concern carrying a person. Each is the conservative option and puts a person, a proof load or a rule between the patient and the shortfall. None of them is a test: no person is carried until the TRL 4 proof loads, including the 285 kg static proof load of the wheel and tyre, and the wet ramp test have passed (DLT-BLD-001, sections 5 and 6). DoliTrail is not certified medical or rescue equipment.

## Context

DLT-CAL-001 v0.1 left R3 (carry load) and R5 (brake holds on descents) at risk, and R7 (portable) and R8 (lift over obstacles) not met. Each was posed as Proposed, awaiting Amish, with options and a recommendation.

## Decision

Table 1. Decisions

| # | Requirement | Option chosen | Effect (DLT-CAL-001 v0.2) | Condition |
| --- | --- | --- | --- | --- |
| O1 | R3, wheel and tyre margin | **A:** keep the 20 inch cargo wheel and prove it with a 285 kg static proof load before any person is carried | No change to the wheel, cost or mass. R3 met if the proof load holds; until then the wheel (0.70) and tyre (0.53 of twice the wheel load on their ratings) are unproven. The proof load is a TRL 4 step, written into the build plan's first checks and safety stops S4 and S5 | Moving to B, a heavier 20 inch tricycle wheel and a 20 x 2.4 cargo tyre (about USD 30 more, 0.6 kg heavier), only if the proof load fails; the proof load is then repeated |
| O2 | R5, grip on a wet descent | **A:** a hold-back strap from the rear bearer's hip belt to the rear pole ends, plus a rule to lift and carry on wet clay steeper than 20 per cent | BOM line 17 (USD 6, 0.2 kg) and a D-ring on the rear bearer's hip belt; hold-back loops on the rear pole ends in the model. The rear bearer holds the shortfall of about 7 kg-force on wet clay at 30 per cent; worst case 402 N if the wheel slides fully, a factor of 12 on the webbing's assumed 5 kN. Tyre grip factor at 20 per cent on wet clay is 1.37. R5 met with the bearer's help, not by the kit alone | The rule is on the fitting card and in safety stop S5 |
| O3 | R7, kit mass | **A:** two bags carried by the two bearers | BOM line 12 becomes two bags (USD 15 more, 0.3 kg). Kit 15.5 kg (with the O2 and O4 parts) in bags of about 6.9 kg and 8.7 kg, each within R7, but not one load for one person | None |
| O4 | R8, lifting over a 400 mm step | **A:** four bearers at steps over about 250 mm, the two helpers lifting at webbing handles on the cross stubs | BOM line 16 (two handles, USD 6, 0.2 kg); handles wrapped round the cross stubs in the model, checked clear of the struts, set screws, wheel and brake. About 36 kg per person at a 400 mm step. R8 met with four people, not two | The rule is on the fitting card and in safety stop S5 |

## Consequences

- Requirement status (DLT-REQ-001 v0.3): R3 at risk to met if the proof load holds; R5 at risk to met with the bearer's help; R7 not met to each load met, not one load for one person; R8 not met to met with four people. No requirement was restated.
- Estimated cost: USD 455 to USD 482 against the USD 1,500 value-engineering target (USD 1,018 under). Kit 14.8 to 15.5 kg; fitted 12.3 to 12.5 kg; rolling weight 142.5 kg, so twice the wheel load is still 285 kg.
- Model: 83 of 83 constructability checks pass (75 before; eight new checks for the lift handles and hold-back loops). STEP and STL, general arrangement DLT-DWG-001 Rev P3, the concept media with blueprint DLT-DWG-010 Rev P2, the build plan pictures (two new joint close-ups) and `media/model.glb` are regenerated.
- New open decision O5 in `docs/06-design-decisions.md`: below the 250 mm threshold two bearers still lift about 71 kg each, by up to 300 mm.

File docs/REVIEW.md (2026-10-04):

# Review note: DoliTrail

## Session 2026-09-30: scaffolded

### What was done

- Repository created from kit 1.6.0 at TRL 1, target TRL 2.
- `docs/01-problem.md` (DLT-PRB-001 v0.1): problem with cited evidence, users, environment, constraints, prior work, open questions.
- `docs/02-concept.md` (DLT-PRC-001 v0.1): how it works, components, patent design-arounds, shared blocks, safety.
- `docs/03-requirements.md` (DLT-REQ-001 v0.1): 9 proposed requirements.
- `README.md` with concept rationale, burning platform, where it could be used, and what sparked the idea.

### Next

- Run `/populate` to bring the repo to a strong TRL 2 with concept media.

## Session 2026-10-03: TRL 2 (populate)

Run as the first half of `/to-trl3` under Amish's pre-approval of 2026-10-03: "start with the first 14 repos from the list of 29 projects. I pre-approve the batch runs along with any recommendations you come up with. I also accept any cost overruns or variations from the assumed scope cost." and his instruction of the same day for batch 2: "Proceed with the remaining 15 scaffolds". Kit 1.7.0 installed.

### What was done

- `docs/01-problem.md` (DLT-PRB-001 v0.2): constraints restated (value-engineering target, clamps on bare pole), open questions settled, first co-design candidates, safety section.
- `docs/02-concept.md` (DLT-PRC-001 v0.2): how it works, components with BOM numbers, key design choices, first-order numbers, design-arounds kept, safety.
- `docs/03-requirements.md` (DLT-REQ-001 v0.2): R1 to R9 with targets unchanged; R10 and R11 added; TRL 3 status.
- Concept media from `cad/src/concept_media.py`: `media/hero.png` (1.75 m person), `media/cutaway.png` (cut through the front clamps), `media/exploded.png` (BOM callouts), `media/flow.png` (where the weight goes, estimates), `media/concept-blueprint.png`, `.pdf` and `.svg` (DLT-DWG-010), `media/model.glb` (1.7 MB, coarse tessellation) and `media/viewer.html`.
- `bom/bom.csv`: 15 priced lines.

### Results

- One wheel under the patient's hips keeps the kit inside the doli's own width; the clamps reach every pole size in the problem statement.

### Requirements not met

- R3, R5, R7 and R8 (see TRL 3).

### Decisions made under the pre-approval

DLT-DDR-001, items D1 to D9: one wheel; V clamps on telescoping arms with hand bolts; cable disc brake with a parking lock; pole loops on slings; 20 inch cargo wheel with a solid axle; rated load and reference doli; first-trial kits in the ambulance; first co-design candidates (not approached); R10 and R11 added.

### Safety concerns

- The doli rolls on one wheel and can tip sideways; bearers keep both hands on the poles.

## Session 2026-10-03: TRL 3 (advance and build plan)

Run as the second half of `/to-trl3` under the same pre-approvals, which count as the TRL 2 approval. Not committed or pushed (batch run).

### What was done

- `cad/src/model.py`: parametric build123d model of the kit on the reference doli (two 60 mm bamboo poles at 550 mm centres); 75 of 75 constructability checks pass (wheel in the fork with 15 mm mud clearance, axle nuts on the plates, caliper on its lobe and clear of spokes, arms in the stubs, liners on the pole, the clamp closing on 40 and 80 mm poles, bolts clear of the pole, strap and bed 100 mm or more above the tyre, 150 mm ground clearance, width). Exports `cad/step/dolitrail-assembly.step`, `dolitrail-kit.step`, `reference-doli-context.step`, the fork unit, side arm, upper jaw and lever mount, and STL of the arm, jaw, liners and lever mount.
- `docs/04-calcs/01-sizing.md` (DLT-CAL-001 v0.1) with `docs/04-calcs/sizing.py` and `results.csv`.
- `cad/src/sheets.py`: general arrangement `cad/drawings/DLT-DWG-001` (SVG, PDF, PNG) at Rev P2, with section A-A at 1:10.
- `cad/src/build_plan_media.py`: `docs/05-build-plan/overview.png`, 6 making sketches `cad/drawings/DLT-DWG-101` to `106`, 8 joint close-ups and 9 step pictures.
- `docs/05-build-plan.md` (DLT-BLD-001 v0.1), `docs/06-design-decisions.md` (DLT-DEC-001 v0.1), `docs/decisions/0001-trl2-review-decisions.md` (DLT-DDR-001) and `docs/decisions/0002-design-for-construction.md` (DLT-DDR-002).
- `cad/src/product_model.py` (appearance model) and render scenes exported with `.kit/export_views.py` to `/home/claude/renders/dolitrail` for hero, exploded and detail views; photoreal renders and cards are made on Amish's Mac.
- `project.yaml`: trl 3, trl_target 3, `design_state: constructable`, evidence listed; `budget_usd` unchanged. README leads with `media/render-hero.png` and has a "Building the prototype" section.

### Results

- Rolling weight 142 kg (120 kg patient, 10 kg doli, 12.3 kg fitted kit).
- Level trail: about 14 kg per bearer against 65 kg carried by two bearers, 79 per cent less (estimate). On a 30 per cent descent with the brake on, the front bearer holds about 46 kg (estimate).
- Brake factor 1.23 on a wet 30 per cent grade; tyre grip factor 1.44 on a wet ramp and 0.84 on wet clay.
- Clamps: 3.96 kN slip resistance per pole, wet (factor 2.6); bamboo crushing factor 2.0 to confirm.
- Lowest structural factor on yield at twice the rated load: 2.02 (struts).
- Width 680 mm on the reference doli; fitting about 4.7 min (estimate); kit 14.8 kg in the bag.
- Value-engineering target: USD 1,500. Estimated cost of the constructable design: USD 455 (USD 1,045 under the target).

### Requirements not met or at risk

R3 and R5 are at risk; R7 and R8 are not met. Each is posed below for Amish to decide. R9 is under the value-engineering target. R2 and R4 rest on estimates.

### Decisions for Amish

All four are recorded in DLT-DEC-001 as **Proposed, awaiting Amish**.

**D-A1. R3, wheel and tyre margin.**
- State: the fork unit, arms and clamps carry twice the rated load with a factor of 2.02 on yield, but the wheel's catalogue rating (200 kg assumed) is 0.70 of twice the wheel load and the tyre's (150 kg) is 0.53 of it. Cause: no light bicycle-type wheel or tyre is catalogue-rated for twice a 142 kg load.
- Option A: keep the 20 inch cargo wheel and show the margin by a 285 kg static proof load of the bought wheel and tyre before any person is carried. Effect: R3 met if the proof load holds; cost and mass unchanged.
- Option B: a heavier 20 inch tricycle wheel (13 gauge spokes, about 300 kg rating) and a 20 x 2.4 cargo tyre (about 200 kg). Effect: wheel about 1.05 and tyre about 0.70 of twice the load on ratings, still needing the proof load for the tyre; about USD 30 more and 0.6 kg heavier (worsens R7).
- Option C: a 10 inch scooter wheel with a drum hub (3.00-10 tyre, about 190 kg). Effect: about 0.67 on rating; about USD 20 more, 2.4 kg heavier, a new brake and 54 mm less ground clearance.
- **Recommendation: A**, moving to B only if the proof load fails. Ratings are working loads with their own unstated margin, so only a proof load shows the real one.

**D-A2. R5, grip on a wet descent.**
- State: the brake holds (factor 1.23), and the tyre holds on a wet test ramp (1.44), but on wet clay or mud the tyre grip factor is 0.84: the wheel would slide with about 7 kg-force unheld. Cause: tyre friction on mud is about equal to the slope.
- Option A: a hold-back strap from the uphill (rear) bearer's hip belt to the rear pole ends, plus the rule to lift and carry on wet clay steeper than 20 per cent. Effect: the bearer holds the shortfall; R5 met with the bearer's help, not by the kit alone; about USD 6 and 0.2 kg.
- Option B: a lever-dropped steel drag claw behind the wheel, hinged on the rear stub. Effect: grip factor about 1.5 on mud (estimate); about USD 35 and 1.1 kg (worsens R7); can catch on roots.
- Option C: a mud tyre with taller knobs (friction about 0.45). Effect: grip factor about 1.08, a thin margin; about USD 10 and 0.1 kg.
- **Recommendation: A.** It keeps a person in control of the load on the worst ground and costs almost nothing; C can be added later if trail tests show the margin is needed.

**D-A3. R7, kit mass.**
- State: 14.8 kg in one bag (12.3 kg fitted). Cause: the steel frame with its bolts (7.8 kg) and the wheel and brake (3.4 kg) alone pass the R7 figure.
- Option A: two bags carried by the two bearers, who walk in together: the fork unit with the wheel, brake and pump (about 6.9 kg with its bag), and the arms, jaws, bolts, lever mount, straps and harnesses (about 8.3 kg). Effect: each load within R7, but not one load for one person; about USD 15 and 0.3 kg.
- Option B: lighter parts: aluminium-handled T-bolts, 1.2 mm wall arms, an alloy hub. Effect: about 13.6 kg, still not met; structural factors stay above 2 on paper; about USD 25.
- Option C: an aluminium frame, TIG welded. Effect: about 11.5 kg, still not met; about USD 120; cannot be repaired by a village welder.
- **Recommendation: A.** Two bearers always walk to the patient, and the steel frame stays repairable.

**D-A4. R8, lifting over a 400 mm step.**
- State: two bearers would each lift about 71 kg from knuckle height to about 1,170 mm (chest height). Cause: the tyre hangs 720 mm below the poles, so the poles must rise 450 mm for the wheel to clear the step.
- Option A: four bearers at steps over about 250 mm: the two extra helpers lift at two webbing handles on the cross stubs. Effect: about 36 kg each, as on a doli today; R8 met with four people, not two; about USD 6 and 0.2 kg.
- Option B: padded shoulder yokes so the two bearers lift the pole ends onto their shoulders (about 1,350 mm). Effect: the wheel clears, but each bearer takes about 71 kg on the shoulders; about USD 20 and 1.2 kg (worsens R7).
- **Recommendation: A.** Villages already carry in relays, and 71 kg per person to chest height is not a safe lift.

### Decisions made under the pre-approval

- DLT-DDR-002: design for construction, changes C1 to C11 and assumptions A1 to A5.
- Sandbags before people: no person carried until the proof loads and the wet ramp test pass; the first person is a healthy volunteer.
- Appearance model departures (renders only): bamboo and cloth colours for the family's doli, a 1.75 m mannequin standing beside the doli on its far side (never between the camera and the product), and a repeated front right clamp for the detail view.

### Build plan findings

- Design changes for construction (2026-10-03), all in DLT-DDR-002: a welded fork unit with cross stubs fore and aft of the wheel and four struts; telescoping side arms with rubber-lined V saddles; upper jaws with two T-handle bolts; T-handle set screws; a webbing cross strap above the wheel; the caliper on a lobe of the left dropout plate; a strapped lever mount; pole loops on slings; a solid axle in open slots; clamps on bare pole with the bed lashing slid aside; a wheel bag; a pump and ties.
- A clamp that closes round a pole cannot pass a bed covering sewn round the pole as a sleeve; such dolis are not fitted until the partner trial decides how (item to confirm 6 in DLT-DEC-001).
- Items to confirm with real parts (wheel, tyre and brake ratings, bamboo crushing, friction, bed fixing, local doli sizes, masses, the brake patent's lapse) are in DLT-DEC-001.

### Safety concerns

- Patient transport over steep wet ground: not certified medical or rescue equipment. Safety stops S1 to S6 in DLT-BLD-001 gate welding, loading, the wet ramp test, any trail trial with a person and every fitting.
- One wheel: the doli can tip sideways; on a 15 per cent side slope each bearer's hands hold about 16 kg up or down.
- Wet clay descents: grip, not the brake, is the limit (D-A2).
- Steps: lifting by two bearers is unsafe (D-A4).
- Bamboo can split under a clamp; clamps are hand tight only and poles are checked at every fitting.

### Recommended next step

Amish decides D-A1 to D-A4. Then the design looks ready for TRL 4 once Amish chooses to start it: build one kit, proof-load the frame and the wheel with CalRig, run the wet ramp test with sandbags, and take the first checks in DLT-BLD-001 section 5 to the first co-design candidate.

## 2026-10-03: photoreal renders

Rendered with Blender Cycles on Amish's Mac from `cad/src/product_model.py`; captioned with `.kit/photo_caption.py`; `media/card.png` and `media/social-preview.png` made with `.kit/cards.py`. Views: hero, exploded, detail. image_qc passes and `render.py --check` has no FAIL.

## 2026-10-03: Amish's requirement decisions carried out (round 2)

Amish on 2026-10-03: "i agree with all the 46 recommendations you provided. please proceed." For DoliTrail this decides O1 to O4 of DLT-DEC-001 as recommended: 6A (R3), 7A (R5), 8A (R7) and 9A (R8). Recorded in `docs/decisions/0003-requirement-decisions-round-2.md` (DLT-DDR-003). Not committed or pushed (batch run).

### Changes

- `cad/src/model.py`: hold-back strap (BOM line 16): two closed webbing end caps 40 mm deep over the rear pole ends, two 25 mm legs to a 40 mm steel ring, a 600 mm tail with a cam buckle to the rear bearer's hip belt. Lift handles (line 17): a 40 mm webbing band sewn shut round each cross stub, 100 mm off centre (front left, rear right), with a 130 mm hand loop and foam grip. Sixteen new checks; 91 of 91 constructability checks pass. STEP and STL regenerated (the new parts are in `dolitrail-assembly.step` and `dolitrail-kit.step`).
- `bom/bom.csv`: line 12 is now the wheel bag; new lines 16 (hold-back strap, USD 6), 17 (two lift handles, USD 3 each) and 18 (parts bag, USD 15), each with its price basis.
- `docs/04-calcs/sizing.py`, `results.csv` and `01-sizing.md` v0.2: new results [K13] to [K15], [B9] to [B11], [S12], [H5] to [H7]; assumptions A13 (carry limit) and A14 (webbing strength).
- `docs/03-requirements.md` v0.3 (targets unchanged; Amish quoted; status of R3, R5, R7, R8 and R9), `docs/02-concept.md` v0.3, README cost and key components.
- `docs/05-build-plan.md` v0.2: three new rows in Table 1; section 3.11 two bags; new sections 3.12 hold-back strap and 3.13 lift handles; step 9 adds the hold-back strap; first checks for the wheel proof load before use, the hold-back strap, each bag's mass and the four-person step; safety stops S3 and S5.
- Pictures: general arrangement DLT-DWG-001 Rev P3 (lift handles shown, note line); new making sketches DLT-DWG-107 (hold-back strap) and DLT-DWG-108 (lift handle); new joints 9 (lift handle) and 10 (hold-back cap); overview and steps 1 to 9 redrawn (the fork unit now carries the handles); concept media redrawn (hero, exploded with the handles, cutaway, blueprint DLT-DWG-010 Rev P2 key figures, `model.glb`).
- Register `docs/06-design-decisions.md` v0.2: O1 to O4 moved to Decisions made; items to confirm 1, 5 and 10 updated or added; value engineering updated.
- Appearance model `cad/src/product_model.py`: hold-back strap and lift handles in the hero and exploded views; scenes re-exported to `/home/claude/renders/dolitrail`.

### New results

- R3: frame, arms and clamps factor 2.01 on yield at twice the rated load (was 2.02; 0.2 kg of handles added). Each bought wheel is proof-loaded to 285 kg (twice the 142.5 kg rolling weight) for 10 minutes before use; the heavier tricycle wheel only if it fails. Met on paper for the frame; the wheel and tyre are shown by the proof load.
- R5: brake 1.23 and wet ramp grip 1.44 (verification test met on paper). Wet clay: 0.84 at 30 per cent, so the bearers lift and carry above 20 per cent, where grip is 1.37. The hold-back strap would take the 65 N shortfall on a 30 per cent wet clay patch met by surprise; strength factor about 25 against the whole along-slope force (webbing strength to confirm).
- R7: two bags of 7.2 kg (fork unit, wheel, brake, handles, pump) and 8.3 kg (everything else), each under 10 kg; the whole kit is 15.5 kg, so it is not one load for one person.
- R8: four people at steps, about 36 kg each; 350 N on each handle (webbing factor about 29; stub bending 13 MPa). With two bearers it is still about 71 kg each, which the drill rules out.
- R2: unchanged at about 4.7 min; the handles stay on the frame and the hold-back strap goes on with the harness loops.
- R9: Value-engineering target: USD 1,500. Estimated cost of the constructable design: USD 482 (USD 1,018 under the target). `budget_usd` unchanged.
- Mass: fitted kit 12.5 kg; rolling weight 142.5 kg; level-trail bearer load about 14 kg (79 per cent less), unchanged.

### For Amish

- New open decision O5 in the register. State: R7 still reads "kit mass at or below 10 kg and carried by one person" and R8 "two bearers lift", but decisions 8A and 9A meet them with two bags and four people. Option A: restate R7 as "kit carried in two bags, each at or below 10 kg, one per bearer" and R8 as "four people (two bearers, two helpers at lift handles) lift the fitted doli over a 400 mm step without removing the wheel, about 36 kg each". Option B: keep the wording and report both as met only per bag and with four people. **Recommendation: A**, so the requirements match the design that will be tested at TRL 4. Nothing in the build changes either way.
- The photoreal renders (`media/render-*.png`), card and social preview do not show the hold-back strap or lift handles yet; re-render on the Mac from the re-exported scenes.

### Safety

- The hold-back strap helps on wet descents; it does not replace the rule to lift and carry on wet clay steeper than 20 per cent. Two bearers never lift the fitted doli over a step alone.
- Every bought wheel is proof-loaded with sandbags under safety stop S3 before any person is carried; sandbags before people is unchanged.

### Recommended next step

Amish decides O5. The design then looks ready for TRL 4 when Amish chooses to start it.

## 2026-10-04: Amish's requirement decisions carried out (round 3)

Amish on 2026-10-04: "For round 3, I agree with all your proposed recommendations". For DoliTrail this decides O5 of DLT-DEC-001 as recommended (1A). Recorded in `docs/decisions/0004-requirement-wording-round-3.md` (DLT-DDR-004). Wording and records only; no geometry. Not committed or pushed.

### Changes

- `docs/03-requirements.md` v0.4: R7 restated as "two bags of 10 kg or less, one per bearer"; R8 restated as "four people at steps, two at the lift handles"; Amish quoted.
- `docs/04-calcs/01-sizing.md`: R7 note updated to the restated wording.
- `docs/06-design-decisions.md` v0.3: O5 moved to Decisions made; Open decisions now "None."
- No model, BOM, drawing or media change was needed.

### New results

- R7: met as designed; two bags of 7.2 and 8.3 kg, one per bearer.
- R8: met as designed; four people, about 36 kg each.
- R9: Value-engineering target: USD 1,500. Estimated cost of the constructable design: USD 482 (USD 1,018 under the target). Unchanged.

### For Amish

Nothing new.

## 2026-10-04: photoreal renders redone after the round-2 and round-3 decisions

Views: hero, exploded, detail; cards regenerated; image_qc passes and `render.py --check` has no FAIL.

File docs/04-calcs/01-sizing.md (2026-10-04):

---
doc_id: DLT-CAL-001
title: DoliTrail sizing calculations
project: DoliTrail
doc_type: Calculation note
version: "0.2"
status: Draft
date: '2026-10-03'
author: Amish Chadha
license: CERN-OHL-S-2.0
revisions:
- version: "0.1"
  date: '2026-10-03'
  author: Amish Chadha
  change: First issue at TRL 3, on the constructable design of DLT-DDR-002
- version: "0.2"
  date: '2026-10-03'
  author: Amish Chadha
  change: "Amish's round-2 decisions 6A to 9A (DLT-DDR-003): wheel proof load [S12]; hold-back strap and the 20 per cent carry rule [B9] to [B11]; two bags [K13], [K14]; lift handles and four lifters [H5] to [H7]; masses, loads and cost re-run"
---

# DoliTrail sizing calculations

On paper, the kit lets two bearers roll a 120 kg patient on the reference doli along a level trail holding about 14 kg each instead of carrying 65 kg each, clamps to poles of 40 to 80 mm without tools, and keeps the doli's own width. The steel frame and clamps carry twice the rated load with a factor of at least 2.0 on yield, and the disc brake has a factor of 1.23 on a wet 30 per cent grade. Amish decided the four results that fell short on 2026-10-03 ("i agree with all the 46 recommendations you provided. please proceed."; DLT-DDR-003): each bought wheel is proof-loaded to 285 kg before use (R3); a hold-back strap ties the uphill bearer to the rear pole ends, and the doli is lifted and carried on wet clay steeper than 20 per cent, where the tyre grip factor is 1.37 (R5); the kit travels in two bags of about 7.2 and 8.3 kg (R7); and four people lift at steps, about 36 kg each, two of them at new lift handles on the cross stubs (R8). The estimated parts cost is USD 482, under the value-engineering target of USD 1,500.

Every figure comes from `docs/04-calcs/sizing.py`, which imports the parametric model (`cad/src/model.py`), so the sizes here are those of the STEP files, the drawings and the build plan. Tags in square brackets match the script output and `docs/04-calcs/results.csv`. These are screening estimates for a paper proof of concept; every one is checked by test at TRL 4.

> **Safety:** DoliTrail carries a person over steep, wet and uneven ground. These numbers are for a design review, not a release for use. No patient is carried until the frame, clamps and wheel have been proof-loaded and the brake has been tested on a wet ramp with a dummy load (DLT-BLD-001, sections 5 and 6).

## 1. Method and assumptions

The fitted doli is a rigid beam on three supports: the wheel under the patient's hips and the two bearers' pole loops at the ends. Because the bearers choose how much to lift, the wheel takes the weight and the bearers carry only what balances the doli in pitch and roll. Pitch balance comes from the error in placing the wheel under the combined centre of mass; on a slope, from the weight's component along the slope acting at the height of the centre of mass. Brake, grip, clamp friction, structural stress and lift height follow by hand methods in the script.

*Table 1. Assumptions.*

| # | Assumption | Value | Basis |
| --- | --- | --- | --- |
| A1 | Rated load | 120 kg patient on a 10 kg doli; fitted kit 12.5 kg; rolling weight 142.5 kg | R3; two 60 mm bamboo poles, sticks, cloth and rope |
| A2 | Centre of mass | 100 mm above the pole centres; wheel within 100 mm of it | Patient lying on a sagging bed; hip mark on the fitting card |
| A3 | Steadying | Each bearer holds 5 per cent of the rolling weight | Estimate |
| A4 | Tyre grip | 0.35 on wet clay or mud (knobbly tyre); 0.60 on a wet timber or concrete ramp | Estimates |
| A5 | Brake | Sintered pads 0.35 wet; 2.0 kN per pad at about 150 N hand pull, held by the parking lock; 203 mm rotor | To confirm with the bought brake |
| A6 | Clamp | Rubber on wet bamboo 0.35; 2.0 kN per clamp (two M8 bolts at 1.0 kN, hand tight) | Estimate |
| A7 | Bamboo | A 40 mm length of 60 mm culm takes 4.0 kN across its diameter in V jaws | To confirm on real poles |
| A8 | Side load | 30 per cent of the wheel load at the tyre (side slopes, roots) | Estimate |
| A9 | Steel | ERW tube, yield 210 MPa, E 205 GPa | IS 1161 YSt 210 |
| A10 | Wheel and tyre ratings | Wheel 200 kg, tyre 150 kg at maximum pressure | Seller ratings, to confirm |
| A11 | Rolling resistance | 0.08 on a dirt trail | Estimate |
| A12 | Masses of bought parts | Wheel 2.60 kg, brake set 0.81 kg, harness 0.75 kg each, wheel bag 0.60 kg, parts bag 0.30 kg, pump kit 0.35 kg, hold-back strap 0.20 kg, lift handles 0.10 kg each | Catalogue values and estimates, to confirm |
| A13 | Carry limit (decision 7A) | Lift and carry on wet clay steeper than 20 per cent | Amish, 2026-10-03 |
| A14 | Webbing strength | 25 mm polyester 5 kN, 50 mm polyester 10 kN, breaking | Typical values, to confirm |

## 2. Geometry

*Table 2. Kit geometry.*

| Tag | Quantity | Value |
| --- | --- | --- |
| [G1] | Wheel diameter, 20 x 2.125 tyre | 514 mm |
| [G2], [G3] | Pole centres and diameters the clamps take | 450 to 600 mm; 40 to 80 mm |
| [G4] | Tyre contact below the pole centres | 720 mm |
| [G5], [G6] | Width on the reference doli; largest pole centres for 700 mm | 680 mm; 570 mm |
| [G7] | Spigot inside its stub at the widest setting | 77.5 mm |
| [Q3] | Cross strap above the tyre | 174 mm |

## 3. Mass (R7)

*Table 3. Masses.*

| Tag | Item | kg |
| --- | --- | --- |
| [K1] | Fork unit | 2.65 |
| [K2] | Side arms, four | 3.27 |
| [K3], [K4] | Upper jaws; jaw liners | 0.60; 0.21 |
| [K5] | T-handle bolts and set screws | 1.05 |
| [K6], [K7] | Wheel; disc brake set | 2.60; 0.81 |
| [K8] | Lever mount | 0.37 |
| [K9] | Bearer harnesses, two | 1.50 |
| [K15] | Hold-back strap; lift handles, two | 0.20; 0.20 |
| [K10] | Straps, two bags, card, ties, pump and puncture kit | 2.06 |
| [K11] | Kit, both bags | 15.53 |
| [K12] | Kit fitted to the doli, with the lift handles | 12.52 |
| [K13] | Wheel bag: fork unit with lift handles, wheel, brake, pump kit, bag | **7.21** |
| [K14] | Parts bag: arms, jaws, bolts, lever mount, straps, harnesses, hold-back strap, bag | **8.31** |

**R7 (decision 8A):** the kit travels in two bags carried by the two bearers, who walk in together: 7.2 kg and 8.3 kg, each under 10 kg. The whole kit (15.5 kg) is still more than one person's 10 kg; the requirement is restated as two bags of 10 kg or less, one per bearer (decision 1A of 2026-10-04, DLT-DDR-004), and is met.

## 4. Bearer loads (R4)

*Table 4. Bearer loads.*

| Tag | Case | Result |
| --- | --- | --- |
| [L1] | Rolling weight | 142.5 kg |
| [L3] | Carrying today, per bearer: two bearers (four) | 65 kg (32.5 kg) |
| [L4] | Level trail, pitch balance on the heavier end | 13.2 kg |
| [L5] | Level trail, average per bearer with steadying | 13.7 kg |
| [L6] | Reduction against two bearers carrying | **79 per cent** (R4 met, estimate) |
| [L7] | 30 per cent descent, brake on, downhill bearer | 45.6 kg (estimate) |
| [L8] | Pull to keep rolling on a level trail | 56 N each (estimate) |
| [L9], [L10] | 15 per cent side slope: roll moment; force at each hand | 170 N m; 154 N (about 16 kg) |

## 5. Brake and grip on a 30 per cent grade (R5)

*Table 5. Brake and grip.*

| Tag | Quantity | Value |
| --- | --- | --- |
| [B1], [B2] | Along-slope force; brake torque needed | 401 N; 103 N m |
| [B3], [B4] | Brake torque available, wet; factor | 127 N m; **1.23** |
| [B5] | Wheel load normal to the slope | 961 N |
| [B6] | Tyre grip factor on wet clay or mud | **0.84** |
| [B7] | Tyre grip factor on a wet test ramp | 1.44 |
| [B8] | Shortfall on wet mud | about 7 kg-force |
| [B9] | Tyre grip factor on wet clay at the 20 per cent carry limit | **1.37** |
| [B10] | Hold-back strap pull on 30 per cent wet clay, wheel at its grip limit | 65 N |
| [B11] | Hold-back strap strength against the whole along-slope force on 30 per cent | 25 (two 25 mm legs; to confirm) |

**R5 (decision 7A):** the brake holds (1.23) and the tyre grips on the wet test ramp (1.44), so the verification test passes on paper. On wet clay or mud the tyre would slide before the brake slips on a 30 per cent grade, so the rule is to lift and carry on wet clay steeper than 20 per cent, where the grip factor is still 1.37. The hold-back strap gives the uphill bearer a direct hold on the rear pole ends on every wet descent; on a patch of 30 per cent wet clay met by surprise it would take the 65 N shortfall while the bearers stop and lift. Taking weight on the downhill bearer lightens the wheel and makes grip worse, which is why the help comes along the slope from the uphill bearer.

## 6. Clamps (R1)

*Table 6. Clamps.*

| Tag | Quantity | Value |
| --- | --- | --- |
| [C1], [C2] | Slip resistance, one clamp; two clamps on one pole | 1.98 kN; 3.96 kN |
| [C3] | Factor on the 1.5 kN pull of R1 | **2.6** |
| [C4] | Bamboo crushing factor at the clamp force | 2.0 (to confirm) |
| [C5], [C6] | Vertical load per saddle; braking pull per clamp | 319 N; 100 N |

The V jaws wedge the pole, so the friction force is 2.83 times the bolt force times the friction coefficient. The vertical load is carried in bearing by the saddles, not by friction. **R1 met on paper**, with the crushing capacity of real bamboo to confirm.

## 7. Structure at twice the rated load (R3)

*Table 7. Structure.*

| Tag | Quantity | Value |
| --- | --- | --- |
| [S1], [S2] | Strut axial load; stress with side load | 2.51 kN; 104 MPa |
| [S3], [S4] | Strut factor on yield; buckling factor | 2.01; 31 |
| [S5], [S6] | Stub; spigot bending stress | 69 MPa; 67 MPa |
| [S7] | Lowest structural factor on yield | **2.01** |
| [S8] | Clamp bolt tension | 1.0 kN each (proof load about 8.4 kN) |
| [S9] | Wheel rating against twice the wheel load | **0.70** |
| [S10], [S11] | Tyre rating against twice the wheel load; against the wheel load | **0.53**; 1.05 |
| [S12] | Wheel proof load before use, twice the rolling weight | **285 kg** |

**R3 (decision 6A):** the fork unit, arms and clamps meet the 2 to 1 margin (lowest factor 2.01 with the lift handles' 0.2 kg added). The wheel and tyre do not on their sellers' ratings, which are working loads with their own unstated margin. Each bought cargo wheel, with its tyre at full pressure, is therefore proof-loaded to 285 kg for 10 minutes before the kit is used; a wheel that fails is replaced by the heavier 20 inch tricycle wheel and 20 x 2.4 cargo tyre (about USD 30 more and 0.6 kg heavier), which is proof-loaded the same way.

## 8. Width, steps and fitting (R6, R8, R2)

*Table 8. Width, steps and fitting.*

| Tag | Quantity | Value |
| --- | --- | --- |
| [W1] | Width on the reference doli | 680 mm (R6 met) |
| [H1], [H2] | Rise of the poles for the wheel to clear a 400 mm step; pole height | 450 mm; 1,170 mm |
| [H3], [H4] | Lift per person: two bearers; four people | 71 kg; **36 kg** |
| [H5] | Pull on each lift handle, four lifting | 350 N |
| [H6] | Stub bending at the strut from a handle at twice its pull | 13 MPa (factor 16 on yield) |
| [H7] | Lift handle webbing strength factor | 29 (to confirm) |
| [T1] | Fitting time, two people | 4.7 min (R2 met, estimate) |

**R8 (decision 9A):** the tyre hangs 720 mm below the poles, so clearing a 400 mm step means lifting the poles from knuckle height to chest height; two bearers would lift about 71 kg each, which is not a safe lift. At steps over about 250 mm four people lift: the two bearers at the pole ends and two helpers at webbing lift handles sewn round the cross stubs (front stub left of centre, rear stub right), about 36 kg each, as on a doli carried by four today. The handles hang below the stubs with 162 mm of hand room under the poles and bed and 69 mm clear of the tyre. Fitting time (T1) assumes the wheel travels fitted in the fork unit; the handles stay on the fork unit and the hold-back strap goes on with the harness loops, so neither adds to it.

## 9. Cost (R9)

Value-engineering target: USD 1,500. Estimated cost of the constructable design: USD 482 (USD 1,018 under the target) [Q1], [Q2]. The decisions add USD 27: the hold-back strap (USD 6), two lift handles (USD 6) and the parts bag (USD 15); the wheel proof load uses the CalRig rig and sandbags. The largest lines are the two harnesses (USD 70), the fork unit (USD 62), the four side arms (USD 60) and the wheel (USD 55).

## 10. Results against the requirements

*Table 9. Results.*

| ID | Result | Status |
| --- | --- | --- |
| R1 | Clamp factor 2.6 wet; crushing factor 2.0 | Met on paper |
| R2 | About 4.7 min | Met on paper (estimate) |
| R3 | Frame 2.01; wheel 0.70 and tyre 0.53 of twice the load on ratings; every wheel proof-loaded to 285 kg before use | Met on paper for the frame; the wheel and tyre are shown by the proof load (decision 6A) |
| R4 | 79 per cent | Met on paper (estimate) |
| R5 | Brake 1.23; grip 1.44 on a wet ramp; 1.37 on wet clay at the 20 per cent carry limit; hold-back strap | Met on paper on the wet ramp; on wet clay met by the carry rule and the hold-back strap (decision 7A) |
| R6 | 680 mm | Met on the reference doli |
| R7 | Two bags, 7.2 and 8.3 kg; 15.5 kg in all | Met per bag (decision 8A); not one load for one person |
| R8 | 36 kg each, four people with two lift handles; 71 kg each with two | Met with four people (decision 9A); not with two |
| R9 | USD 482 | Under the value-engineering target |
| R10 | One pull on the tab | Met by design |
| R11 | Lever 100 to 150 mm behind the pole loop | Met on paper |

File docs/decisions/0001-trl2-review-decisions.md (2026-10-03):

---
doc_id: DLT-DDR-001
title: DoliTrail TRL 2 review decisions
project: DoliTrail
doc_type: Design decision record
version: "0.1"
status: Draft
date: '2026-10-03'
author: Amish Chadha
license: CERN-OHL-S-2.0
revisions:
- version: "0.1"
  date: '2026-10-03'
  author: Amish Chadha
  change: TRL 2 review items decided under Amish's 2026-10-03 pre-approvals
---

# 0001: TRL 2 review decisions

- **Date:** 2026-10-03
- **Status:** decided. Decided by Amish under his pre-approval of 2026-10-03: "start with the first 14 repos from the list of 29 projects. I pre-approve the batch runs along with any recommendations you come up with. I also accept any cost overruns or variations from the assumed scope cost." and his instruction of the same day for this batch: "Proceed with the remaining 15 scaffolds".

## Context

The scaffold (DLT-PRB-001, DLT-PRC-001 and DLT-REQ-001, all v0.1) described a single wheel in a fork under the doli, clamps on the poles, a cable or rod brake, padded harnesses with pole-end cups and quick-release patient straps. It left five open questions: one wheel or two, how much of a route rolls, where kits are kept, what commercial kits exist, and whether a harness shifts load safely. Populating the concept to TRL 2 meant settling these and choosing the main parts. Items that touch safety take the conservative option and say what evidence would relax it. Partners are the first candidates to approach, not agreements. Requirements that the design does not meet are not decided here; they are posed to Amish (DLT-DEC-001).

## Options considered

*Table 1. Options.*

| # | Item | Options |
| --- | --- | --- |
| D1 | Wheels | (a) one wheel under the patient's hips; (b) two wheels side by side; (c) two wheels in line |
| D2 | Pole fixing | (a) rubber-lined V clamps on telescoping arms, hand bolts; (b) ratchet straps only; (c) U-bolts and nuts |
| D3 | Brake | (a) cable disc brake, 203 mm rotor, lever with parking lock; (b) rim brake; (c) hub drum brake |
| D4 | Harness to pole | (a) pole-end cups; (b) webbing pole loops on adjustable slings |
| D5 | Wheel | (a) 20 inch cargo or tricycle wheel, knobbly 2.125 tyre; (b) 16 inch; (c) wheelbarrow wheel |
| D6 | Rated load and reference doli | 120 kg patient (R3), 10 kg doli of two 60 mm poles at 550 mm centres |
| D7 | Kit storage for the first trial | (a) in the ambulance; (b) at the road end; (c) in the village |
| D8 | Co-design partner | 108 ambulance operators, maternal health NGOs, village health committees, rescue groups |
| D9 | Requirements | Keep R1 to R9 and their targets; add patient release and brake reach |

## Decision

- **D1 (a).** One wheel under the patient's hips. The wheel stays inside the doli's own width (R6); the bearers steady it in roll. Conservative consequence: the tipping hazard is named in every document and bearers keep both hands on the poles.
- **D2 (a).** Rubber-lined 90 deg V saddles on four square-tube arms that telescope into the fork unit's stubs, closed by upper jaws and two T-handle bolts each. Straps alone could creep on wet bamboo; U-bolts need spanners and crush thin poles.
- **D3 (a).** Cable disc brake with sintered pads and a lever with a parking lock, on the front right pole. A rim brake fails in mud; a drum hub of the needed torque is heavy and harder to find. The parking lock is required on every kit (conservative), so the doli never relies on a hand to stay put on a slope.
- **D4 (b).** Pole loops on slings fit any pole end and any bearer height; cups would need sizes.
- **D5 (a).** 20 inch cargo or tricycle wheel with a knobbly 57-406 tyre and a solid axle (no quick release, conservative). A 16 inch wheel rolls worse over roots; a wheelbarrow wheel takes no disc brake.
- **D6.** Rated patient 120 kg; reference doli two 60 mm bamboo poles 2.55 m long at 550 mm centres, 10 kg with sticks, cloth and rope.
- **D7 (a).** First trial kits travel in the ambulance and are carried in by the crew, so a service maintains them.
- **D8.** First candidates to approach, in order (none approached yet): a district 108 ambulance operator in Mayurbhanj, Odisha; a maternal health NGO working with village health committees in the same block; a volunteer mountain rescue group for trail technique.
- **D9.** R1 to R9 kept with their targets unchanged. R10 (each patient strap frees with one pull in 3 s or less) and R11 (the front bearer works the brake and lock without letting go) added.
- **Unchanged:** the pitch, the problem, the design-arounds (own clamp geometry and colours; lapse of US7922183B2 to be confirmed) and `budget_usd` (USD 1,500), read as a value-engineering target.

## Consequences

- The kit is a welded steel frame, a bought wheel and brake and sewn webbing; a village workshop and a tailor can make and repair it.
- R3, R5, R7 and R8 fall short or are at risk on paper (DLT-CAL-001); each is posed to Amish in DLT-DEC-001 with options and a recommendation.
- The design is made constructable in DLT-DDR-002.

> **Safety:** D1, D3 and D5 carry the conservative choices: both hands on the poles, a parking lock on every kit and a solid axle. The single-wheel tipping hazard would be relaxed only by trail trials with a dummy load showing that bearers hold it on side slopes.

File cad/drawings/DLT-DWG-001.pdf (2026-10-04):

CONCEPT, NOT FOR FABRICATION | DoliTrail · github.com/BoujeeEnjinia1701/dolitrail

FRONT VIEW
Scale 1:20; looking at the front (along +Y)

TOP VIEW
Scale 1:20; looking down (along -Z)

RIGHT VIEW
Scale 1:20; looking at the right side (along -X)

2100

680 872

720

SECTION A-A
Scale 1:10; looking back along -X through the front clamps

POLE (FAMILY'S DOLI)

SADDLE (2), LINER (4)

JAW (3), T-BOLTS (5)

STUB (1), SPIGOT (2)

WHEEL (6), CUT EDGE

STRUT (1)

MAIN SIZES AND FIGURES (MM UNLESS STATED)
Poles 40 to 80 dia at 450 to 600 centres; reference 60 at 550 Pole centres 720 above ground, level, wheel down
Width over clamps 680 on the reference doli
Wheel 20 x 2.125 (57-406), 514 dia, disc hub, 3/8 axle Cross stubs 30 x 30 x 2 SHS, 320 long, at +/-300
Struts 22.2 x 1.6 tube, 380 long; dropouts 5 plate
Arms 25 x 25 x 1.6 SHS; spigot 230, at least 78 in the stub Clamps: 90 deg V, 5 rubber liner, two M8 T-bolts at 104 centres
Brake: 203 rotor, cable caliper; lever with lock on front right pole
Cross strap 50 webbing round both poles above the wheel
Lift handles (17) on the stubs, 100 off centre; hold-back strap (16) on rear pole ends, not shown Rated patient 120 kg; rolling weight about 142.5 kg
Third-angle; X forward, Y to the left; (n) = BOM line
REV | DESCRIPTION | DATE | BY
P1 | Preliminary GA for TRL 3 (from cad/src/model.py) | 2026-10-03 | AC
P2 | DLT-DDR-002: design for construction | 2026-10-03 | AC
P3 | DLT-DDR-003: lift handles on the stubs; hold-back strap noted | 2026-10-03 | AC
DOLITRAIL | github.com/BoujeeEnjinia1701/dolitrail

## Clamp-on wheel kit on the reference doli: general arrangement

DRAWING NO.
DLT-DWG-001

REV
P3

SHEET
1 of 1

SIZE

## ANSI B

SCALE
1:20

UNITS
mm
PROJECTION | DATE
2026-10-03

DRAWN
Amish Chadha

MATERIAL / NOTES
Kit per bom/bom.csv; poles are the family's doli (reference shown, cut short). PRELIMINARY, NOT FOR FABRICATION
Licensed CERN-OHL-S-2.0 · Design Molecule Lab · designmolecule.com | Generated from cad/src; do not edit by hand

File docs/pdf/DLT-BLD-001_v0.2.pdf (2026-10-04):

D O L I T R A I L · B U I L D P L A N

# DoliTrail prototype build plan

Design Molecule Lab · designmolecule.com

D O C U M E N T CO N T RO L

Document ID | DLT-BLD-001 | Version | 0.2
Status | Draft | Date | 2026-10-03
Author | Amish Chadha | License | CERN-OHL-S-2.0
Project TRL | TRL 3 | Proof of concept
Repository | github.com/BoujeeEnjinia1701/dolitrail
Source | docs/05-build-plan.md @ uncommitted

R EV I S I O N H I STO RY

Version | Date | Author | Change
0.2 | 2026-10-03 | Amish Chadha | Amish's decisions 6A to 9A (DLT- DDR-003): hold-back strap (3.12), lift handles (3.13), two bags (3.11), wheel proof load before use, four lifters at steps; overview, step 9, joints 9 and 10 and sketches DLT-DWG-107 and 108 added or redrawn
0.1 | 2026-10-03 | Amish Chadha | First build plan; design made constructable (DLT-DDR-002)

D R A F T · N O T F O R F A B R I C A T I O N

## DoliTrail prototype build plan

Plan, not yet built. How to make the first DoliTrail kit and fit it to a doli, component by component. Building and testing to it is TRL 4 work. Decisions are kept in the design decisions register ( docs/06-design-decisions.md ), not here.

Safety: DoliTrail will carry a person over steep, wet ground. It is an open engineering reference, not certified medical or rescue equipment. The first kit carries sandbags, never a patient, until the proof loads and the wet ramp test in sections 5 and 6 have passed. Welding, grinding and cutting need eye, hand and hearing protection and a clear, ventilated space.

### 1. What you are building


Figure 1. The kit in build order. One harness is shown laid flat; the lift handles are sewn on the fork unit's stubs.
The kit turns a family's bamboo doli into a wheeled stretcher with a brake. A welded steel fork unit holds a 20 inch wheel; four side arms slide into its two cross stubs and end in rubber-lined V saddles that the bamboo poles sit in, each closed by an upper jaw and two T-handle bolts. A disc brake on the wheel is worked from a lever strapped to the front right pole. A cross strap keeps the bed off the tyre, three patient straps hold the patient, and two harnesses take the pole ends in slings at each bearer's knuckle height. A hold-back strap ties the rear bearer's hip belt to the rear pole ends for descents, and two webbing lift handles sewn round the cross stubs let two helpers lift at steps. The kit walks in with the two bearers in two bags. Eight components are made (the fork unit, side arms, upper jaws, liners, lever mount, harnesses, hold-back strap and lift handles) by cutting, bending, drilling, welding, gluing and sewing; the rest are bought bicycle parts, fasteners, webbing and bags. Parts cost about USD 482. The sizes are for the reference doli: two 60 mm bamboo poles at 550 mm centres; the kit adjusts to poles of 40 to 80 mm at 450 to 600 mm centres.

### 2. What changed to make it buildable

Table 1. Changes from the concept.

Component | The concept had | The buildable design has | Why
Wheel and fork | "A single wheel in a fork under the middle" | A welded fork unit with two cross stubs fore and aft of the wheel, four struts and dropout plates | The stubs pass below the bed and clear of the wheel; the struts form a stiff truss
Pole clamps | "Adjustable clamps with rubber jaws" | Four side arms that slide in the stubs, each with a rubber-lined V saddle, an upper jaw and two T-handle bolts | Fits poles of 40 to 80 mm at 450 to 600 mm centres, by hand

Cross frame
and strap

One frame and a strap The fork unit and arms are the frame; the

| | strap is a webbing loop round both poles above the wheel | Keeps the bed 174 mm above the tyre
Brake | "Cable or rod brake" | Disc brake with the caliper on a lobe of the left dropout plate | Works wet; the mount is part of the welded plate
Lever | "At the front bearer's hand" | A rubber-lined lever mount strapped on the front right pole | A bicycle lever needs a 22.2 mm bar
Harness | "Pole-end cups" | Pole loops on adjustable slings | Fits every pole end and bearer
Wheel fixing | Not stated | Solid axle and nuts in slots open downward | Nothing to open by mistake
Bed | Not considered | Clamps on bare pole; the bed's lashing is slid aside at the four clamp points | The inboard bolt passes beside the pole
Descents on wet ground | Brake only | A hold-back strap: webbing caps over the rear pole ends, legs to a ring, a tail to the rear bearer's hip belt | The tyre can slide on wet clay before the brake slips; the uphill bearer holds the doli back
Steps | Two bearers lift | Two webbing lift handles sewn round the cross stubs for two helpers | Four people share the lift, about 36 kg each
Carrying the kit | One bag | Two bags, one per bearer: about 7.2 and 8.3 kg | Each load stays under 10 kg


Figure 2. Cut across the doli through the front clamps: the poles sit in the saddles, the wheel runs between the stubs.

### 3. Making the components

Make and paint the steel parts in the workshop, glue in the liners and sew the harnesses before the kit goes anywhere near a doli.

### 3.1 Fork unit

What it is and what it is made from. The backbone of the kit: two cross stubs of 30 x 30 x 2 mm square steel tube, 320 mm long, joined by four struts of 22.2 x 1.6 mm round tube to two 5 mm steel dropout plates that hold the wheel axle. The left plate has a lobe that carries the brake caliper. Mild steel tube and plate, welded and painted. How to make it.
Cut the two stubs 320 mm long, square ends. Drill a 9 mm hole in the top face of each, 135 mm either side of the centre, and weld an M8 nut over each hole.
Cut the two dropout plates from 5 mm plate to the outline on the sketch: a slot 10 mm wide running up from the bottom edge, with the axle centre at its top. Add the caliper lobe to the left plate and drill it for the caliper adapter.
Set the stubs in a jig, parallel, 600 mm apart centre to centre and level. Set the plates on a 3/8 inch spacer bar with a 100 mm spacer between them, the axle centre 233 mm below the stub undersides and midway between the stubs.
Cut the four struts about 380 mm long and mitre both ends so they sit flat on the stub underside and on the outer face of the plate, with their centre lines 64 mm either side of the middle.
Tack, check the dropouts are square to the stubs and 100 mm apart, then weld fully. Grind the slot clean, prime and paint.

How it fits the parts next to it.

1.

2.

3.

4.

5.

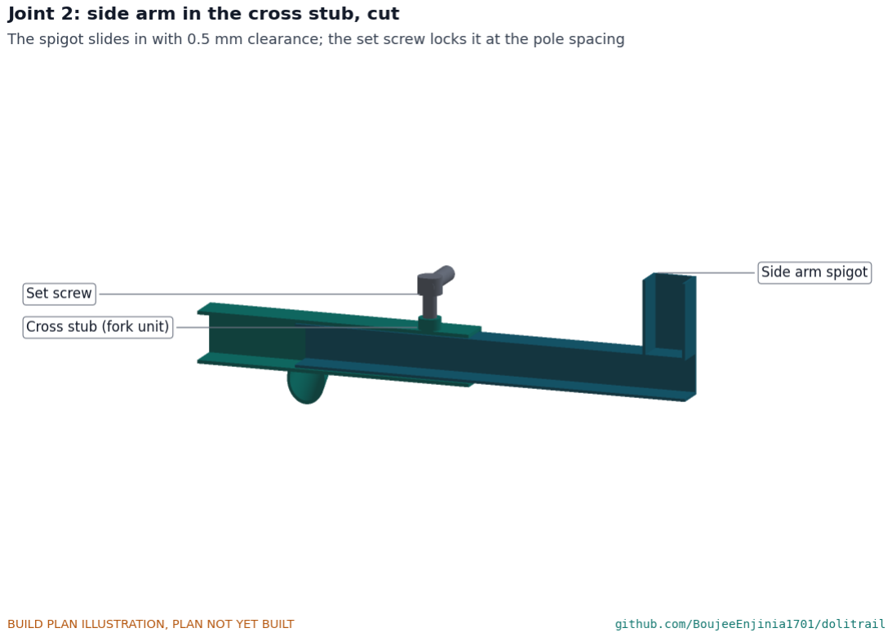
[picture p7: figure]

Figure 3. A side arm's spigot in a cross stub, cut. The set screw locks it.
The side arms' spigots slide into the stub ends with about 0.5 mm clearance each side; a T-handle set screw through each welded nut presses down on the spigot. The wheel axle drops up into the slots (Figure 5), and the caliper bolts to the inside of the lobe (Figure 6).
Check before moving on. A 3/8 inch rod slides through both slots square to the stubs; a stub offcut of the arm tube slides in each stub end by hand without rocking; no weld spatter in the stub bores.

### 3.2 Side arms

What it is and what it is made from. Four L-shaped arms of 25 x 25 x 1.6 mm square tube. Each has a 230 mm spigot that slides into a stub, a 145 mm post welded on top at its outer end, and a 60 x 130 x 4 mm saddle plate on the post carrying a 90 deg V of 3 mm plate, 60 mm wide inside. Two M8 nuts are welded under the plate ears.
How to make it.
Cut four spigots 230 mm and four posts 145 mm from the square tube.
Weld each post on top of its spigot, flush with the outer end, square in both directions (use the same jig for all four).
Cut the saddle plates 60 x 130 mm; drill two 9 mm holes 52 mm either side of the centre line; weld M8 nuts underneath.
Bend 3 mm plate 60 mm wide into a 90 deg V with 30 mm legs, and weld it along the plate centre line, the V running along the pole.
Weld the plate on top of the post, the V centred over it and running square across the spigot, so the pole lies along the doli. Grind, prime and paint.

How it fits the parts next to it.

1.
2.

3.

4.

5.

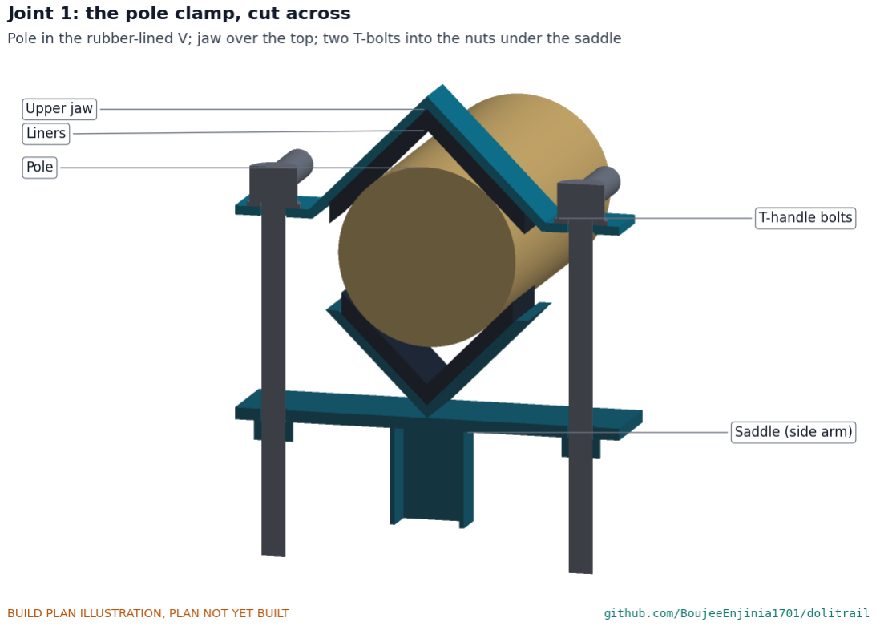
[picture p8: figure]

Figure 4. A pole clamp, cut across: the pole in the rubber-lined V, the upper jaw over it, two T-bolts into the nuts under the saddle.
The bamboo pole lies in the V on its rubber liner; the upper jaw closes over it and the two T-handle bolts pass through the jaw's ears into the nuts under the saddle plate.
Check before moving on. Every arm slides into every stub end; the V is square to the spigot; a 60 mm pipe sits in the V touching both faces.

### 3.3 Upper jaws

What it is and what it is made from. Four strips of 3 x 40 mm steel, 190 mm long, bent into an inverted 90 deg V with two flat ears, 130 mm over the ears.
How to make it.
Cut the strips 190 mm long.
Bend at the centre to 90 deg over a former in a vice; then bend each leg flat to make the ears, so both ears lie level.
Drill 9 mm holes in the ears at 104 mm centres. Deburr and paint.

How it fits the parts next to it. The jaw sits over the pole on its own liner; its ears take the T-handle bolts (Figure 4). On a 40 mm pole the ears come down to about 28 mm above the saddle ears; on an 80 mm pole they rise about 28 mm.
Check before moving on. The jaw's holes line up with the saddle nuts when it sits over a 60 mm pipe in the saddle.

1.
2.

3.

### 3.4 Jaw liners

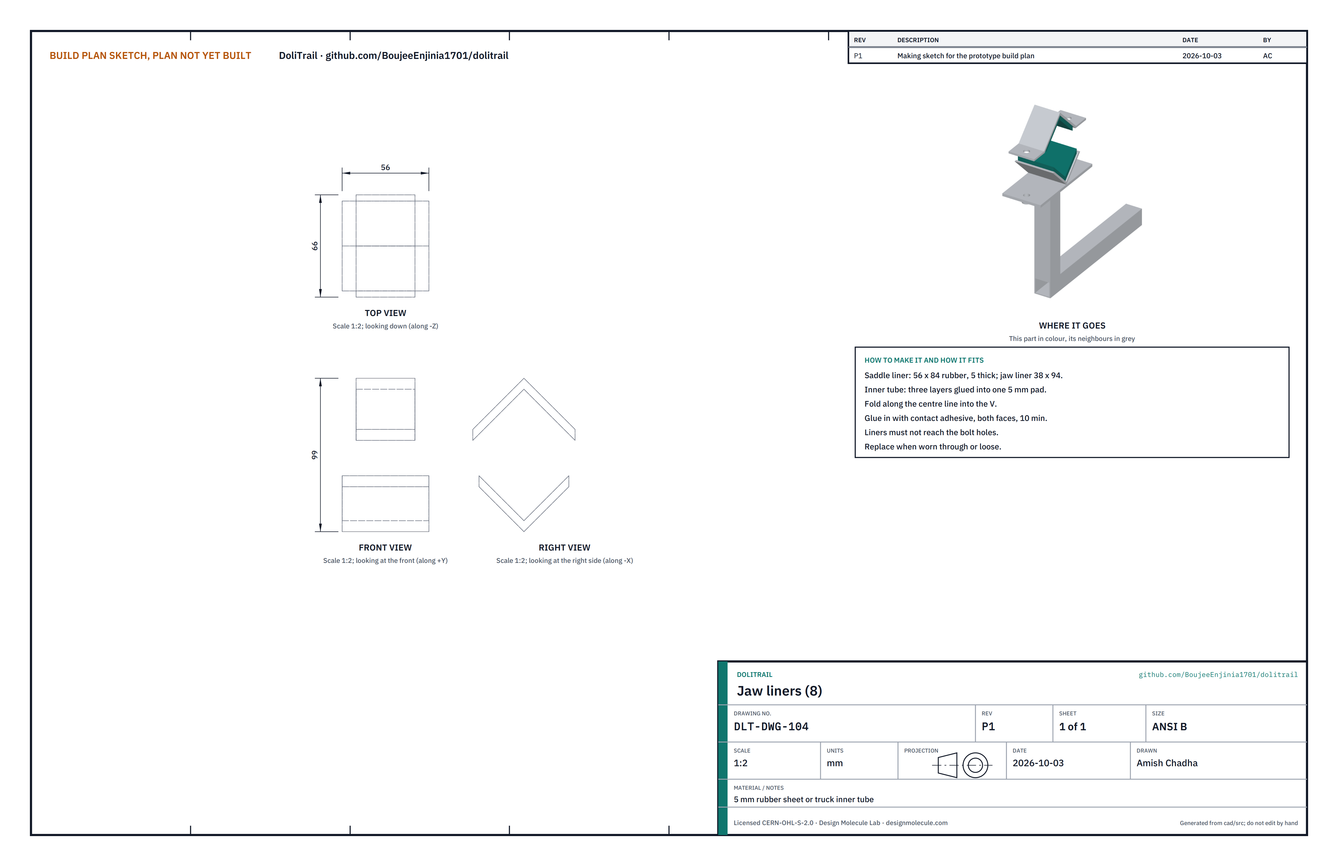
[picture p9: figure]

What it is and what it is made from. Eight pads of 5 mm rubber sheet, or three layers of truck inner tube glued together: 56 x 84 mm for the saddles and 38 x 94 mm for the jaws.
How to make it.
Cut the pads with a sharp knife against a straightedge.
Fold each along its centre line.
Coat the pad and the inside of the V with contact adhesive, wait ten minutes, press in and roll flat.

How it fits the parts next to it. The liner covers both faces of the V and stops short of the bolt holes. The pole bears only on rubber.
Check before moving on. No loose edges; the pad cannot be peeled by hand.

### 3.5 T-handle bolts and set screws (bought)

Buy eight M8 x 130 mm T-handle bolts with 25 mm washers for the clamps, and four M8 x 40 mm T-handle set screws for the arms, zinc plated. Run each into its welded nut once to clean the thread.

### 3.6 Wheel (bought)

Buy a 20 inch (ISO 406) cargo or tricycle wheel with a double-wall rim, 36 spokes of 2.0 mm or heavier and a steel front disc hub 100 mm over the locknuts, with a solid 3/8 inch axle and nuts (not quick release). Fit a 20 x 2.125 knobbly tyre and tube. Bolt the 203 mm rotor to the hub on the left side. Check the seller's ratings against the design decisions register.

1.
2.
3.

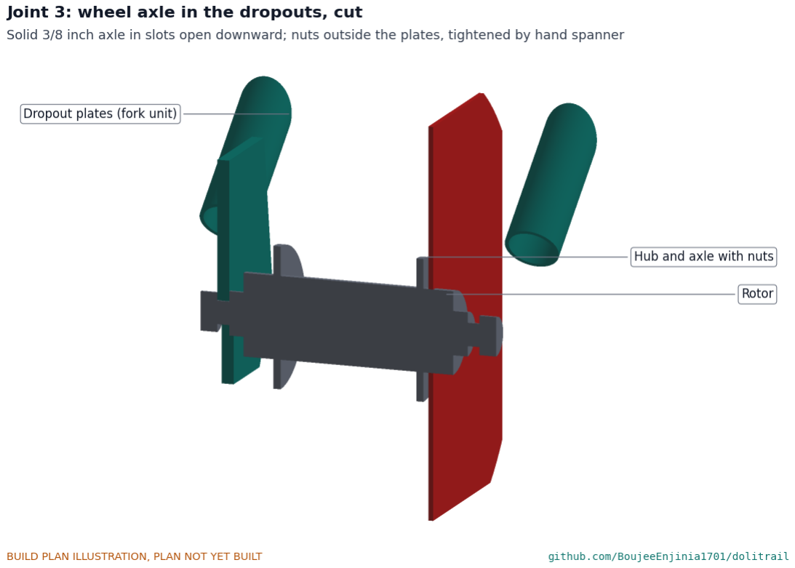
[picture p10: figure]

Figure 5. The axle in the dropout slots, cut: nuts outside the plates.

### 3.7 Disc brake set (bought)

Buy a cable-operated disc caliper with sintered pads and a post-mount adapter, a 203 mm six-bolt rotor, a brake lever for a 22.2 mm bar with a parking lock, and 2.2 m of cable and housing. Fit the adapter to the caliper lobe of the left dropout plate.

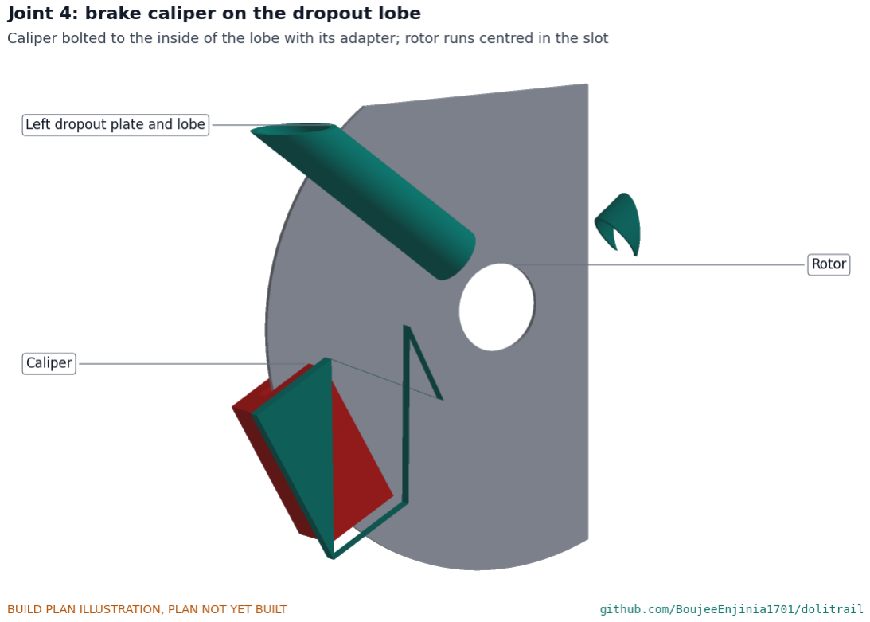
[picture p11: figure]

Figure 6. The caliper bolted to the lobe, the rotor running in its slot.

### 3.8 Lever mount

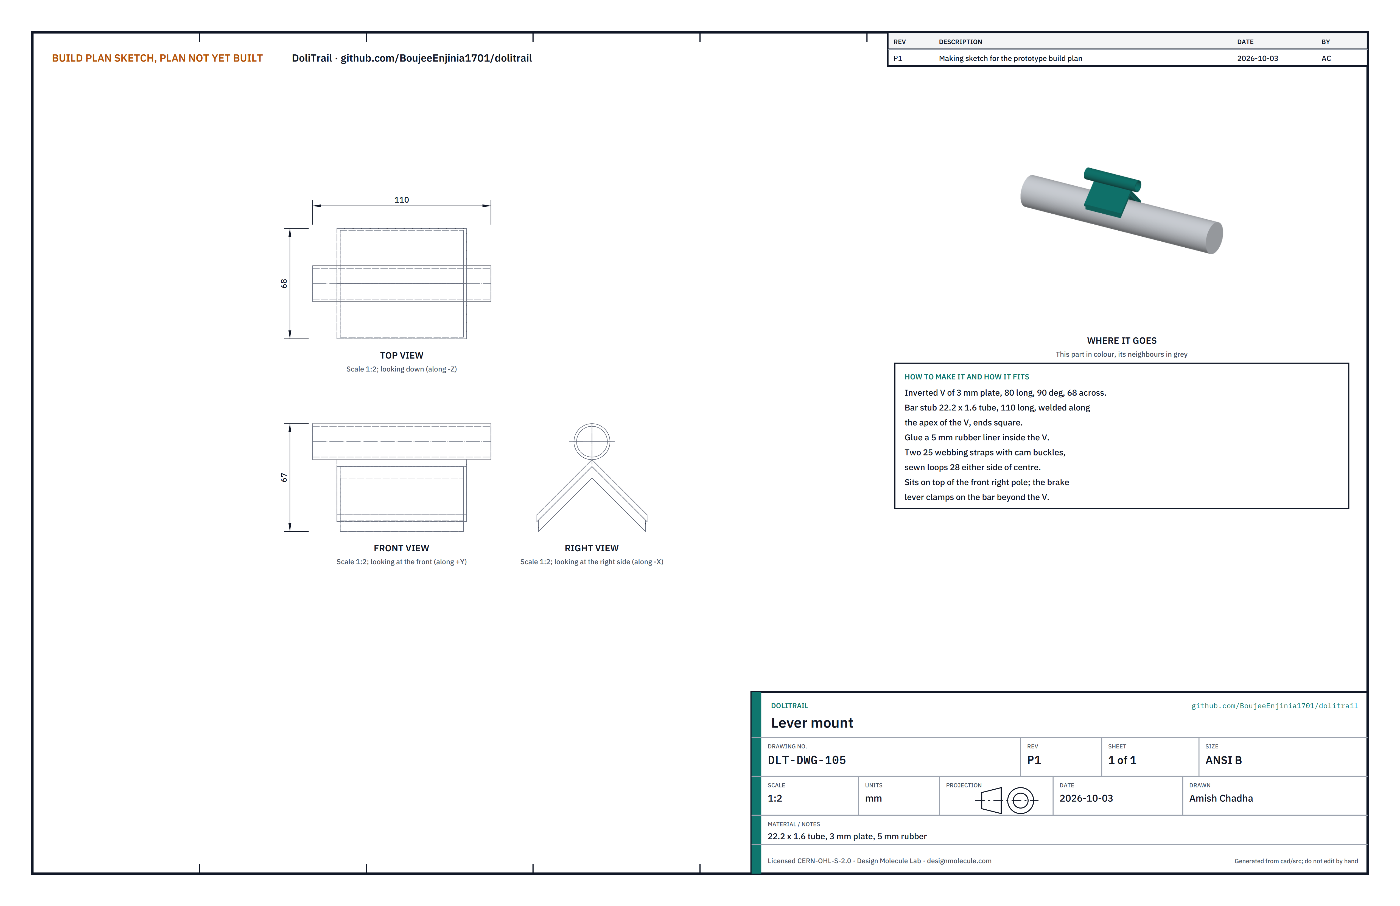
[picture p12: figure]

What it is and what it is made from. A 110 mm stub of 22.2 x 1.6 mm tube, welded along the apex of an 80 mm long inverted V of 3 mm plate, with a 5 mm rubber liner inside the V and two 25 mm webbing cam straps.
How to make it.
Bend 3 mm plate 80 mm wide into a 90 deg V, 68 mm across the open side.
Weld the tube stub along the outside of the apex, centred, ends square. Paint.
Glue a rubber liner inside the V.
Sew two 25 mm webbing straps with cam buckles to pass round the pole, 28 mm either side of the centre.

How it fits the parts next to it.

1.
2.
3.
4.

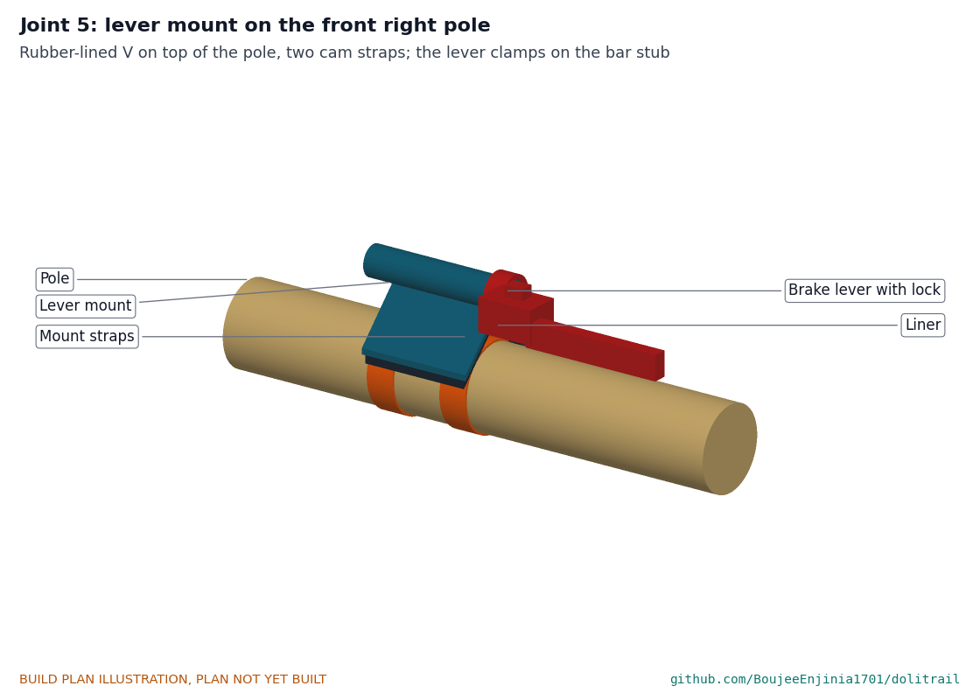
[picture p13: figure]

Figure 7. The lever mount on top of the front right pole, strapped round it; the brake lever clamps on the bar beyond the V.
Check before moving on. On a 60 mm pipe, strapped tight, the mount does not turn when the lever is pulled hard.

### 3.9 Cross strap and patient straps (bought)

Buy 50 mm polyester webbing: one cross strap of 1.6 m with a cam buckle, and three patient straps of 1.8 m with cam buckles and a red pull tab. Heat-seal every cut end.

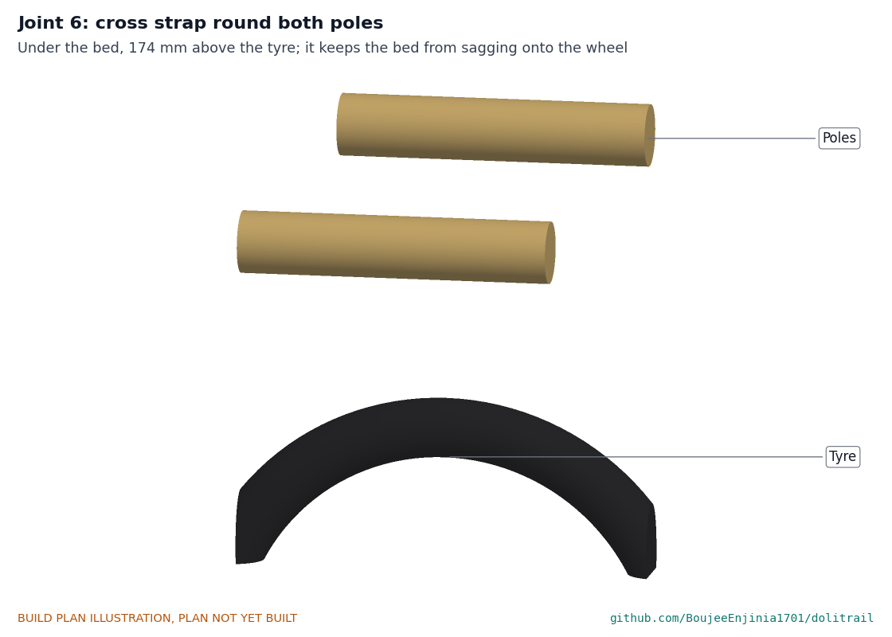
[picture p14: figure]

Figure 8. The cross strap round both poles above the wheel, under the bed.

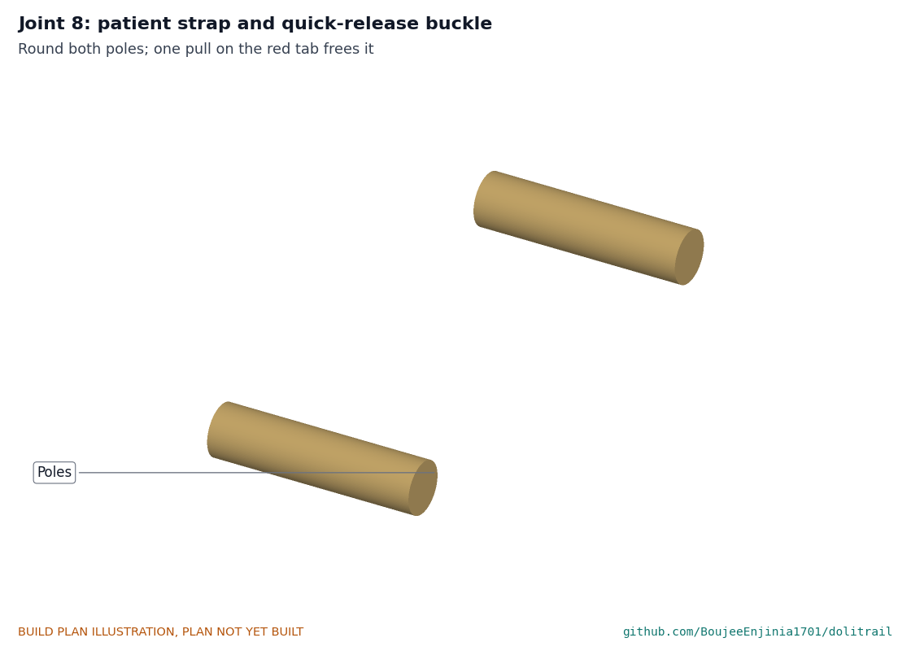
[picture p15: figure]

Figure 9. A patient strap round both poles; one pull on the tab frees it.

### 3.10 Bearer harnesses

What it is and what it is made from. Two harnesses sewn by a tailor from 50 mm polyester webbing: a 1,000 mm hip belt with a foam pad, two padded shoulder straps joined by a chest strap, and two slings, each ending in a pole loop about 110 mm across, with cam buckles to set the length.
How to make it.
Cut and heat-seal the webbing: belt 1,000 mm, shoulder straps 600 mm, chest strap 300 mm, slings 500 mm, loops 400 mm.
Sew the shoulder straps to the belt at the back, 180 mm apart, crossing to the front; add the pads and the chest strap.
Sew a sling to each side of the belt, 660 mm apart; fit a cam buckle in each sling.
Fold each loop and box-and-cross stitch it to its sling with UV-resistant thread.

How it fits the parts next to it.

1.

2.

3.
4.

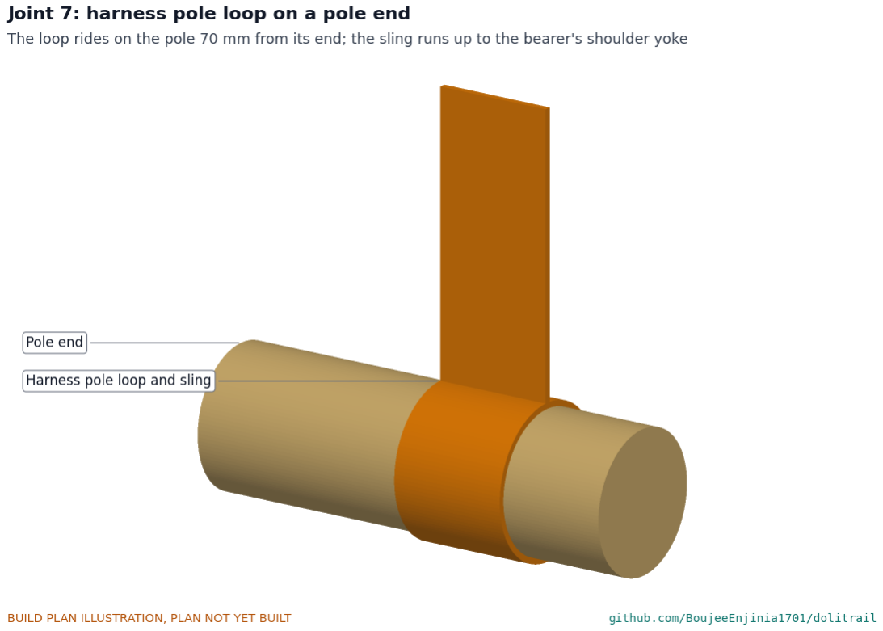
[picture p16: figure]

Figure 10. A harness pole loop on a pole end; the sling runs up to the bearer's yoke. Check before moving on. Hang 50 kg from each loop for one minute: no stitch pulls.

### 3.11 Two carry bags, fitting card, ties and pump (bought)

Two bags, one for each bearer. A canvas wheel bag about 700 x 340 x 560 mm with shoulder straps takes the fork unit with the wheel, brake and lift handles, and the pump kit: about 7.2 kg packed. A canvas backpack of about 45 litres takes the side arms, jaws, bolts, lever mount, straps, harnesses, hold-back strap and the fitting card: about 8.3 kg packed. Also buy an A4 laminated fitting card with the pictures of section 4 and the safety stops; eight hook-and-loop ties; a mini pump, tyre levers, patches and a spare tube.

### 3.12 Hold-back strap

What it is and what it is made from. A Y-shaped strap sewn by a tailor that lets the rear (uphill) bearer hold the doli back on a wet descent. Two closed end caps of 50 mm polyester webbing, 40 mm deep, slip over the rear pole ends, each with a 25 mm cam strap round its mouth; two 25 mm webbing legs, about 420 mm long, run from the caps to a 40 mm steel ring; a 600 mm tail runs from the ring to a cam buckle that clips to the rear bearer's hip belt.
How to make it.
Cut and heat-seal the webbing: two cap pieces of 50 mm webbing 300 mm long, two legs and a tail of 25 mm webbing.
Sew each cap into a closed sleeve that fits over an 80 mm pole end, and sew a 25 mm cam strap round its mouth so it cinches down onto a 40 mm pole.
Sew one end of each leg to the closed end of a cap, and the other end round the ring. Sew the tail round the ring and fit the cam buckle on its free end.
Box-and-cross stitch every joint with UV-resistant thread.

How it fits the parts next to it.

1.

2.

3.

4.

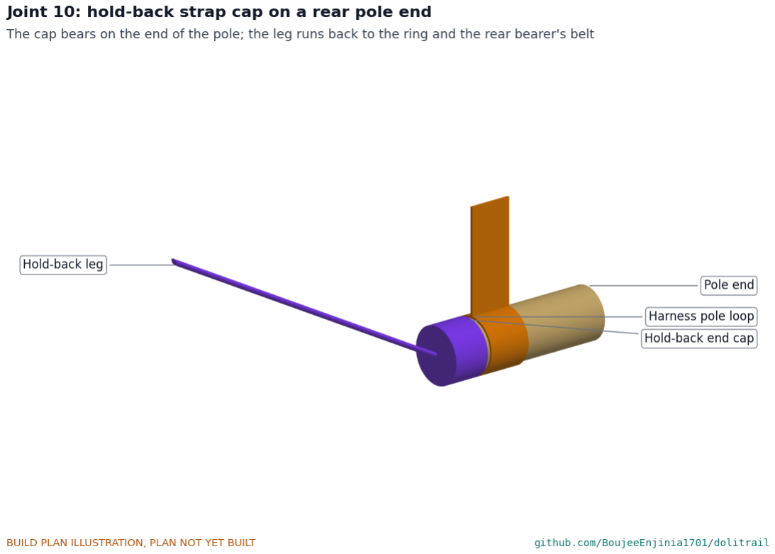
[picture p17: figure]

Figure 11. A hold-back cap on a rear pole end, just behind the harness pole loop.
Each cap goes over a rear pole end, cinched tight, so the pull bears on the end of the pole and the cap cannot slide off backward. It sits about 5 mm behind the harness pole loop. The tail clips to the rear bearer's hip belt and is set so the bearer leans back slightly against it.
Check before moving on. Hang 100 kg from the ring for one minute, with both caps on a length of 60 mm pole: no stitch pulls and neither cap moves.

### 3.13 Lift handles

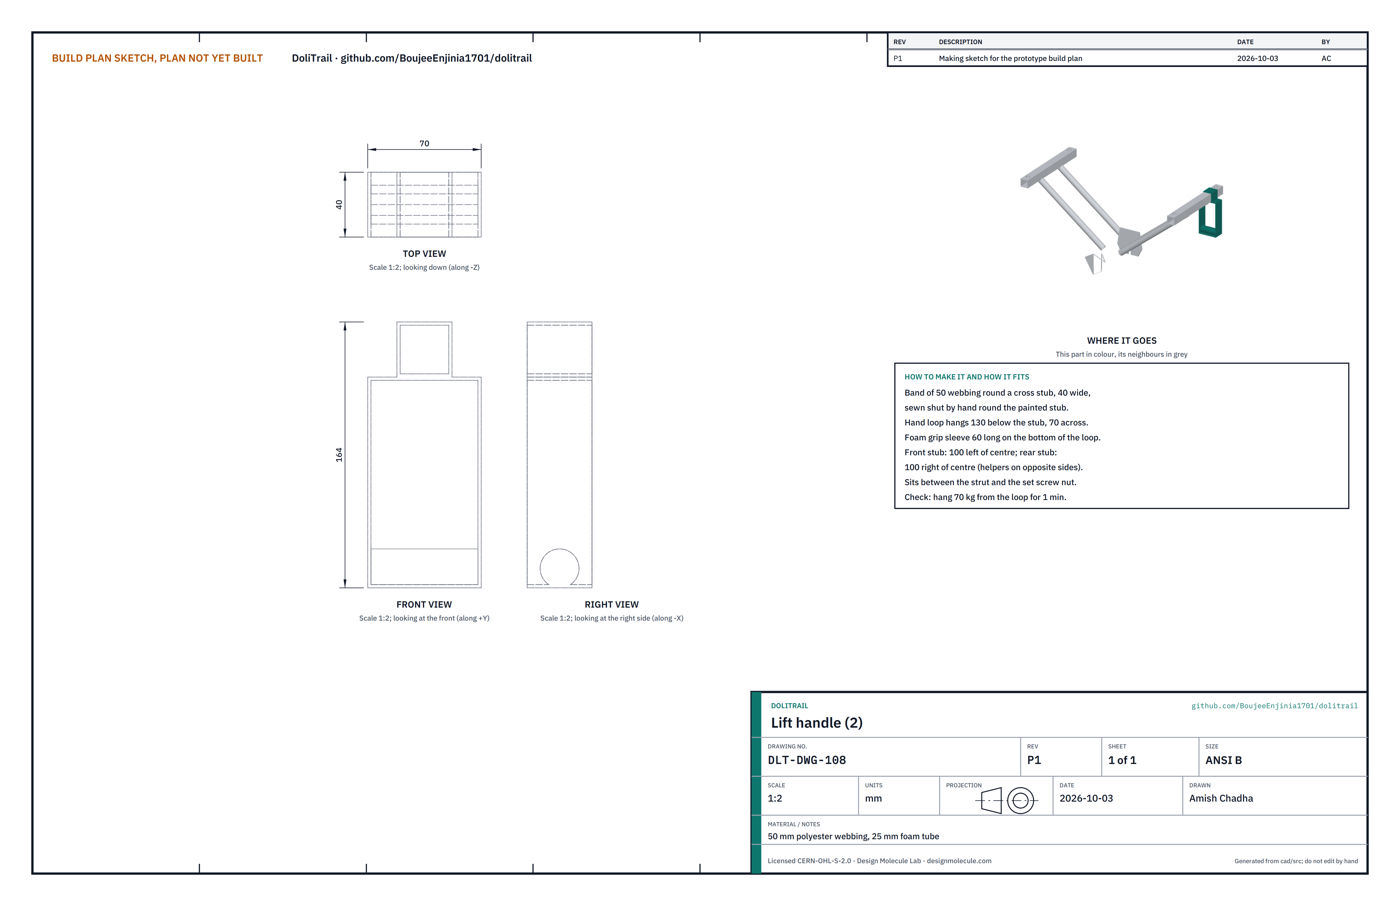
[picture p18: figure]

What it is and what it is made from. Two handles of 50 mm polyester webbing, one on each cross stub of the fork unit, for two helpers at steps. Each is a 40 mm wide band sewn shut round the stub with a hand loop hanging 130 mm below it, 70 mm across, with a 60 mm foam grip on the bottom of the loop.
How to make it.
After the fork unit is painted, wrap the webbing round the front stub 100 mm to the left of its centre and sew it shut by hand, tight on the stub.
Sew the hand loop below it, and slide the foam tube on before closing the loop.
Do the same on the rear stub, 100 mm to the right of its centre, so the two helpers stand on opposite sides of the doli.

How it fits the parts next to it.

1.

2.
3.

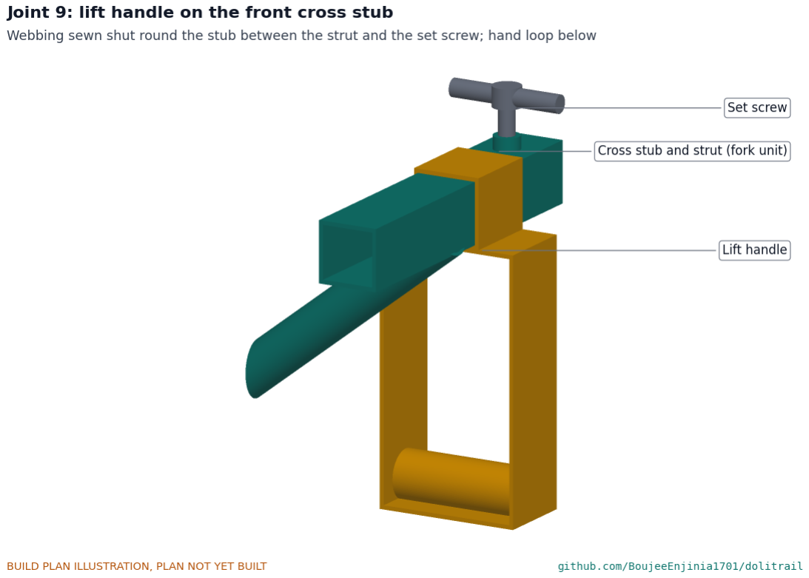
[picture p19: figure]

Figure 12. A lift handle on the front cross stub, between the strut and the set screw.
The band sits between the strut and the set screw's nut, so it cannot slide into either. The loop hangs 69 mm clear of the tyre, with about 160 mm of room for a hand under the pole and the bed. The handles stay on the fork unit and travel in the wheel bag.
Check before moving on. Hang 70 kg from each loop for one minute: no stitch pulls and the band does not slide on the stub.

### 4. Putting it together

Steps 1 to 4 are done once in the workshop; the wheel and the lift handles then stay on the fork unit. Steps 5 to 9 are the fitting to a doli, about five minutes for two people.

Step 1: fit the rotor and the wheel

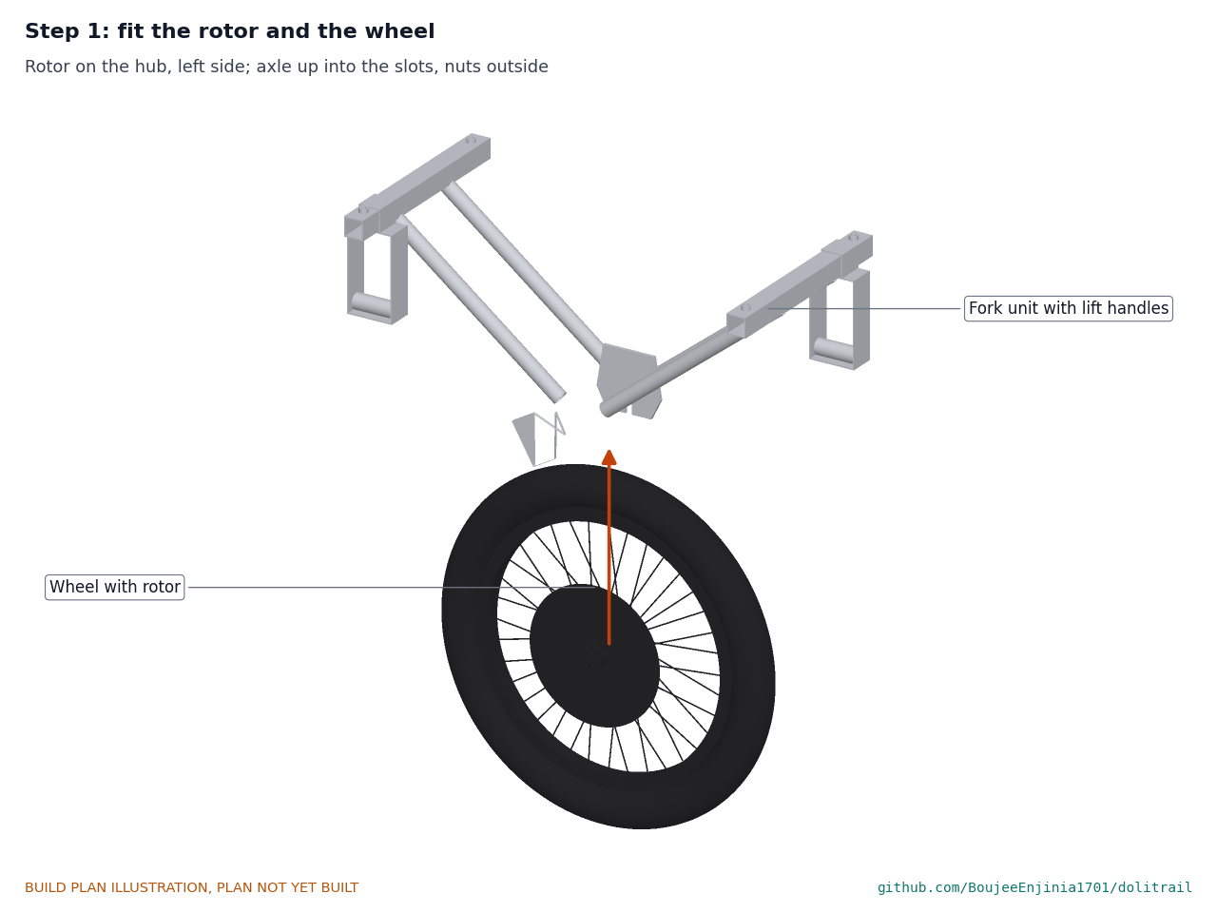
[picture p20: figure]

Bolt the rotor to the hub (left side) to the torque on its packet. Lift the axle up into both slots and tighten the nuts outside the plates with a spanner. Spin the wheel: it runs true and clear of the struts.

Step 2: bolt the caliper to the lobe

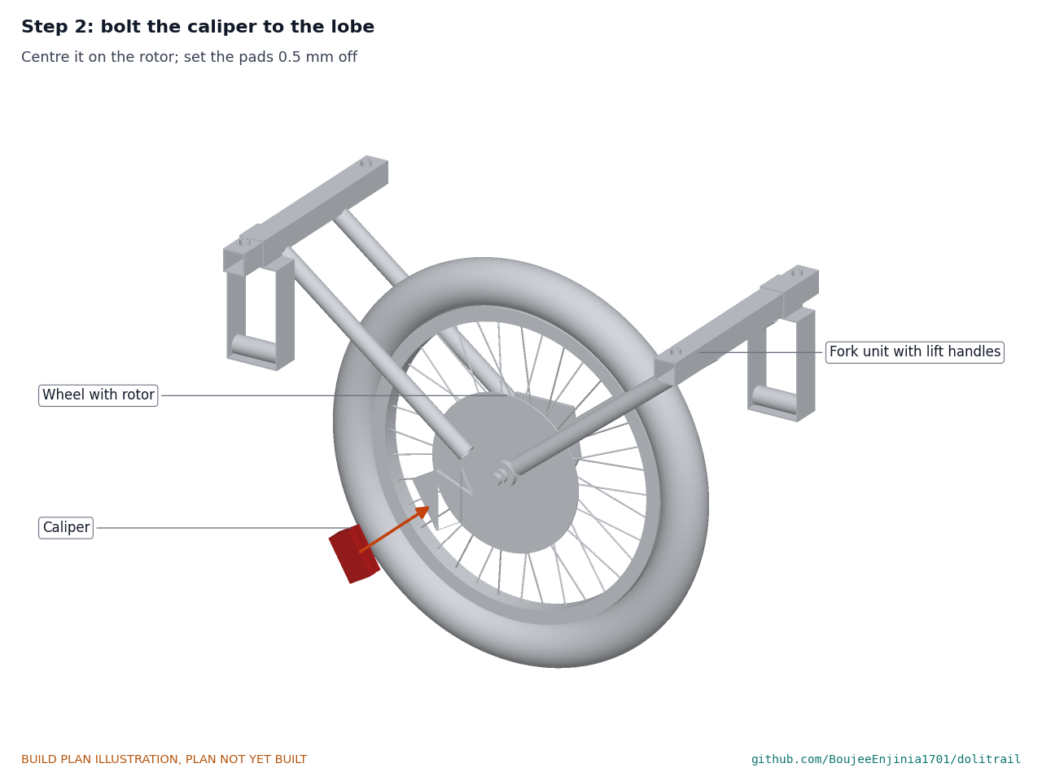
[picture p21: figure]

Bolt the caliper and adapter to the lobe, centre it on the rotor, set the pads about 0.5 mm off, and run the cable through the housing to the lever (the lever stays loose for now).

Step 3: slide the side arms into the stubs

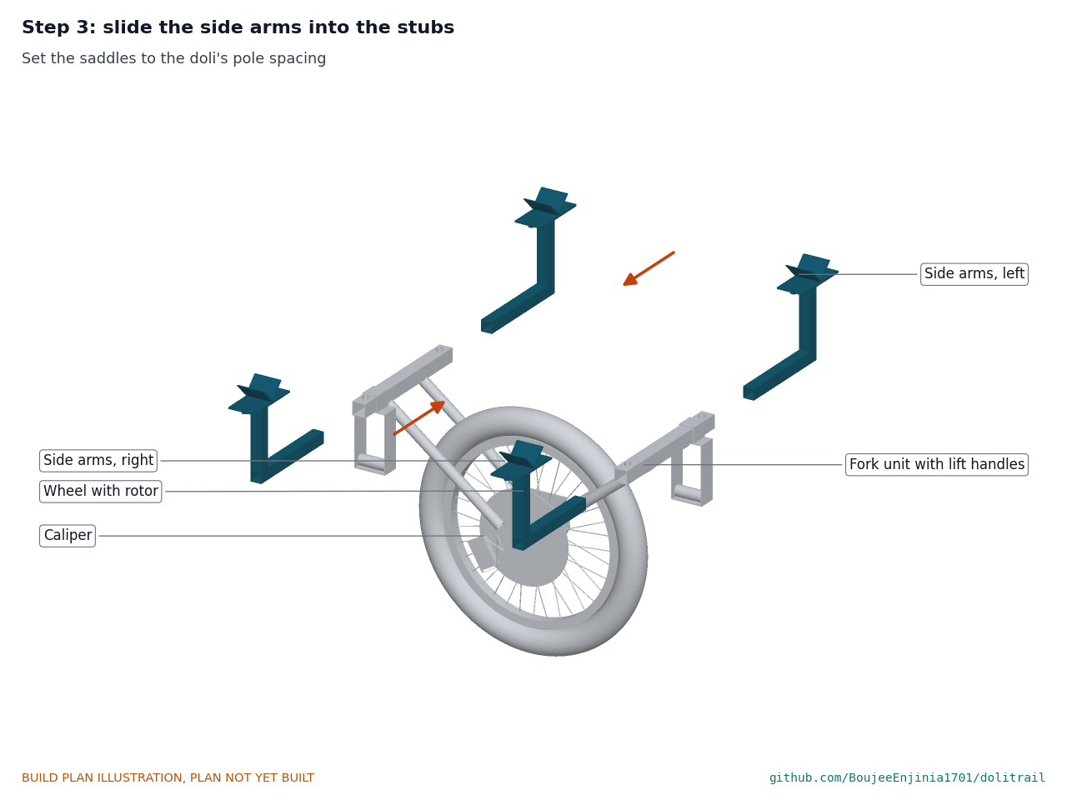
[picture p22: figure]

Slide each arm into its stub end, posts upward and outward. Set the saddles to the doli's pole spacing (measure centre to centre).

Step 4: lock the set screws

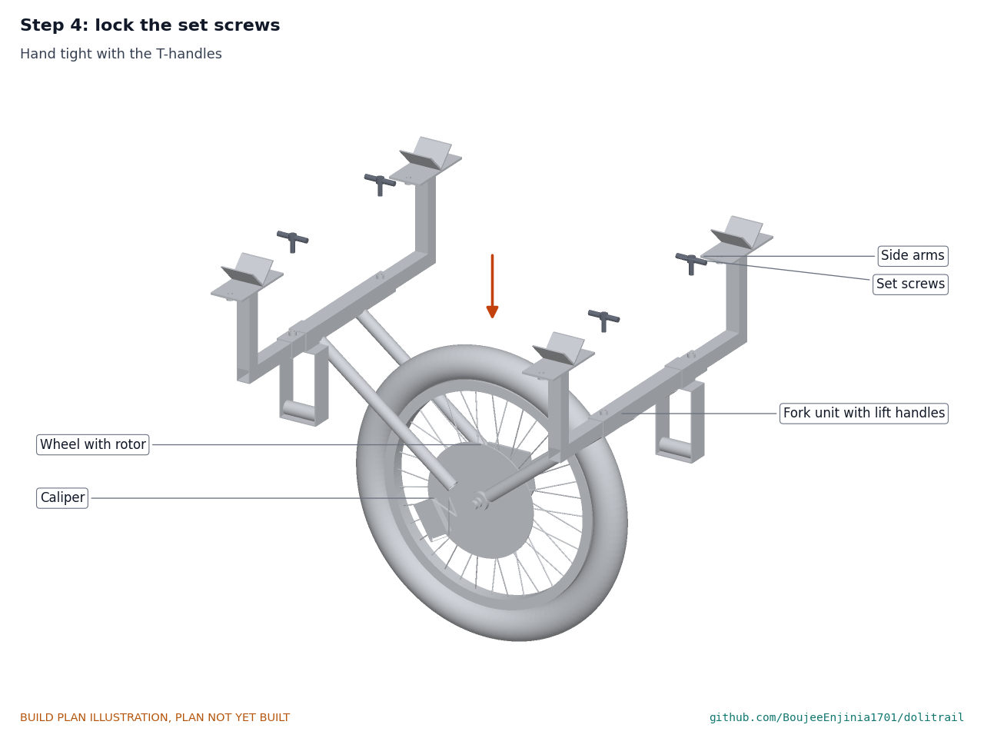
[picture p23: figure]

Tighten the four set screws by hand. Each spigot must be at least 75 mm inside its stub.

Step 5: set the frame under the poles, wheel under the hips

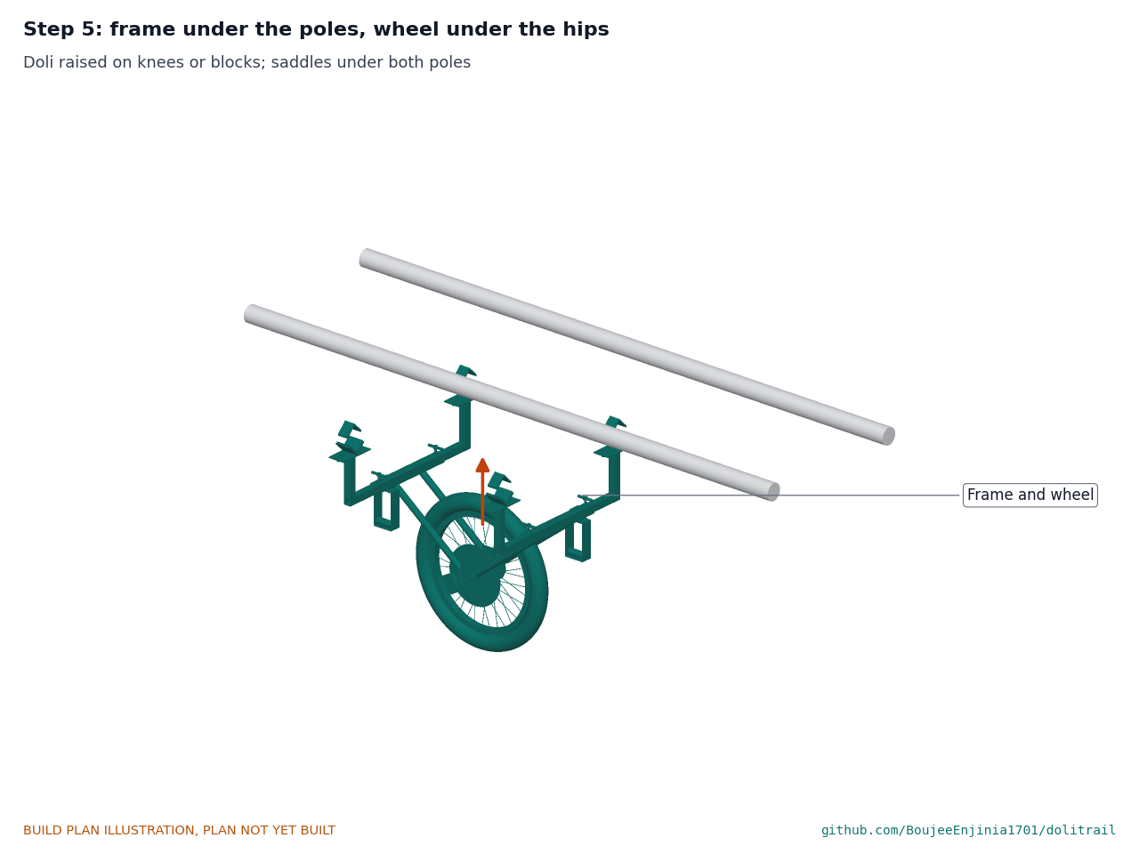
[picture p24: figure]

Two people raise the doli on their knees or on two blocks. Slide the frame under it so the wheel sits under the patient's hips (the belt line), and the saddles sit under both poles at bare pole, sliding any bed lashing about 70 mm aside.

Step 6: close the four clamps

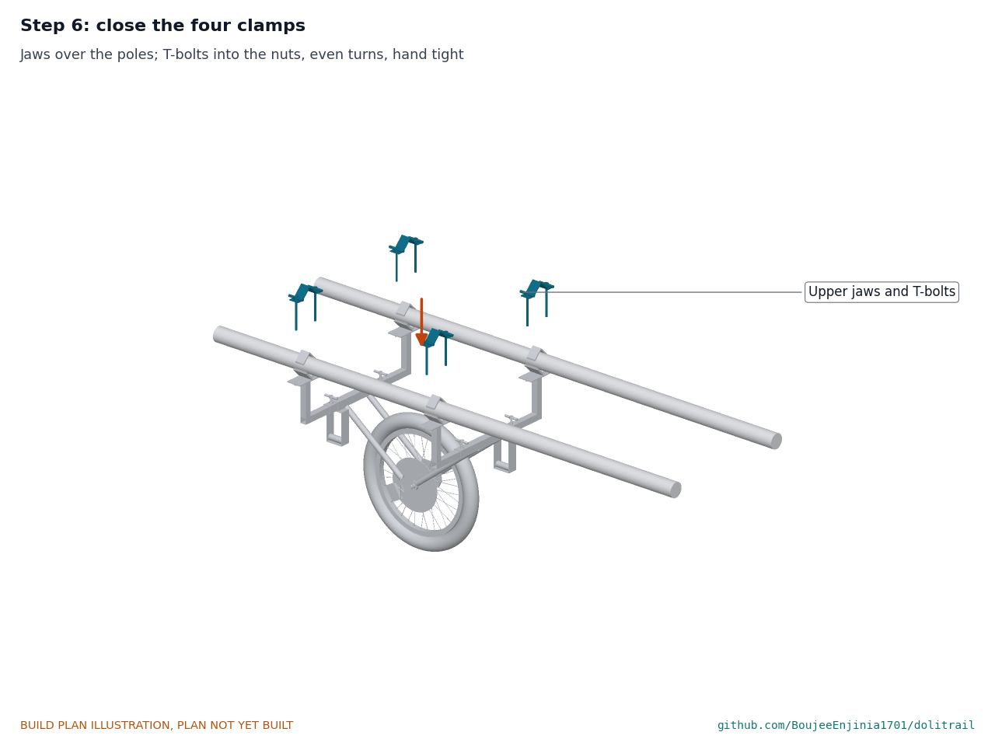
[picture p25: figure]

Lay each upper jaw over its pole; run both T-bolts into the nuts in even turns until the rubber just bulges. Hand tight only, never with a bar.

Step 7: fit the cross strap

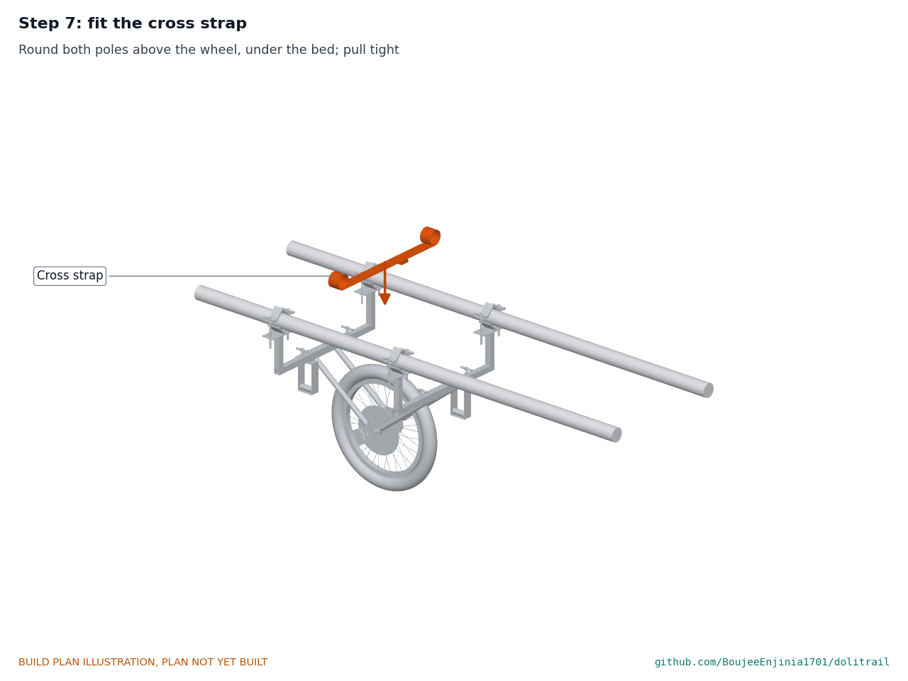
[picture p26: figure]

Pass the strap round both poles just ahead of the wheel's top, under the bed, and pull it tight.

Step 8: fit the lever mount on the front right pole


Strap the mount on top of the front right pole about 150 mm behind where the front bearer's pole loop will sit. Clamp the lever on its bar, blade toward the bearer's hand. Tie the housing along the arm and the pole with the hook-and-loop ties, with no tight bends. Pull the lever: the wheel locks; set the parking lock: it stays locked.

Step 9: patient straps, harness loops and hold-back strap


Pass the three patient straps round both poles at the chest, hips and legs. The bearers put on their harnesses, set the slings to knuckle height and slip the pole loops over the pole ends. Slip the hold-back caps over the rear pole ends behind the rear bearer's pole loops, cinch them, and clip the tail to the rear bearer's hip belt.

### 5. First checks

These are listed here and recorded in a TRL 4 test report. Sandbags stand in for a patient.
Table 2. First checks.

Check | Requirement How | Pass when

Clamp
range
R1 | Close a clamp on 40, 60 and 80 mm bamboo Both liners touch; jaw clear of the saddle
Clamp slip | R1 | Pull the fitted frame along the poles with CalRig | No slip at 1.5 kN on wet poles
Proof load | R3 | 260 kg of sandbags on the fitted doli, wheel on a block, 10 min | No permanent set in the frame, no weld cracks, no clamp movement
Wheel proof load | R3 | Every bought wheel, before the kit is used: 285 kg on the wheel alone, tyre at full pressure, 10 min | No spoke, rim or tyre damage; if it fails, fit the heavier 20 inch tricycle wheel and 20 x 2.4 cargo tyre and repeat
Fitting time R2 | Two people with only the fitting card | Under 5 min
Bearer load | R4 | Load cells in the slings, level trail | Average load per bearer down by 60 per cent or more
Brake hold | R5 | Rated sandbag load on a wet 30 per cent ramp, lever locked | Stays put for 5 min
Hold-back strap | R5 | Rated sandbag load on a wet ramp, rear bearer clipped in, pull measured | The bearer holds the doli back standing upright
Width | R6 | Measure over the clamps | 700 mm or less on the reference doli
Mass | R7 | Weigh each packed bag | Each bag 10 kg or less
Step | R8 | 400 mm step, four people: two bearers and two helpers at the lift handles | Over without removing the wheel; recorded load per person about 36 kg
Release | R10 | Pull each tab, gloved hand | Free in 3 s
Brake reach | R11 | Bearers of 1.5 to 1.8 m | Lever and lock worked without letting go

### 6. Safety stops

Work stops at each point until what is listed is true.
S1, before welding: jig checked square; fire extinguisher and screens in place.
S2, before any load: every weld inspected by eye for cracks and full fusion; every set screw and T-bolt tight; wheel nuts tight.
S3, before the proof loads (frame and every bought wheel): sandbags only; people stand clear of the doli's sides; the wheel rests on a block.
S4, before the wet ramp test: the proof loads (section 5) have passed; a person holds a safety rope to the rear poles; the ramp has a run-out clear of people.
S5, before any trail trial with a person: the ramp test has passed, the bearers have practised with sandbags, and the partner's crew agree. The first person carried is a healthy volunteer, not a patient. Bearers keep both hands on the poles and never roll through moving water. On every wet descent the rear bearer is clipped to the

•
•

•

•

•

hold-back strap; on wet clay steeper than 20 per cent the bearers lift and carry. At steps of more than about 250 mm four people lift, two of them at the lift handles; two bearers never lift the fitted doli over a step alone.
S6, every fitting: clamps checked by shaking the doli; poles checked for splits at the clamp points; brake pulled and the lock tried before anyone is strapped on.

### 7. Tools, skills and workspace

Workshop: a welder (stick or MIG) and a competent welder; angle grinder with cutting and grinding discs; drill press or hand drill with 9 mm bit; bench vice and a 90 deg bending former; files; a flat bench for the jig. Tailor: a heavy sewing machine for webbing, UV-resistant thread, a hot knife for sealing.
Bicycle mechanic: spoke key, 15 mm spanner, Torx or hex keys for the rotor and caliper, cable cutters. Fitting: no tools beyond the kit; the T-handles are turned by hand.
Space: a covered workshop for the steel; a level yard and a test ramp for the checks.

### 8. Where the numbers come from

Model: | cad/src/model.py | (sizes, constructability checks), | cad/step/ | and | cad/stl/ .
Drawings: | cad/drawings/DLT-DWG-001 | (general arrangement) and | DLT-DWG-101 | to | 108 | (making sketches).
Calculations: | docs/04-calcs/01-sizing.md | (DLT-CAL-001), | docs/04-calcs/sizing.py , | docs/04-calcs/
results.csv .
Bill of materials: | bom/bom.csv .
Pictures: | cad/src/build_plan_media.py .

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
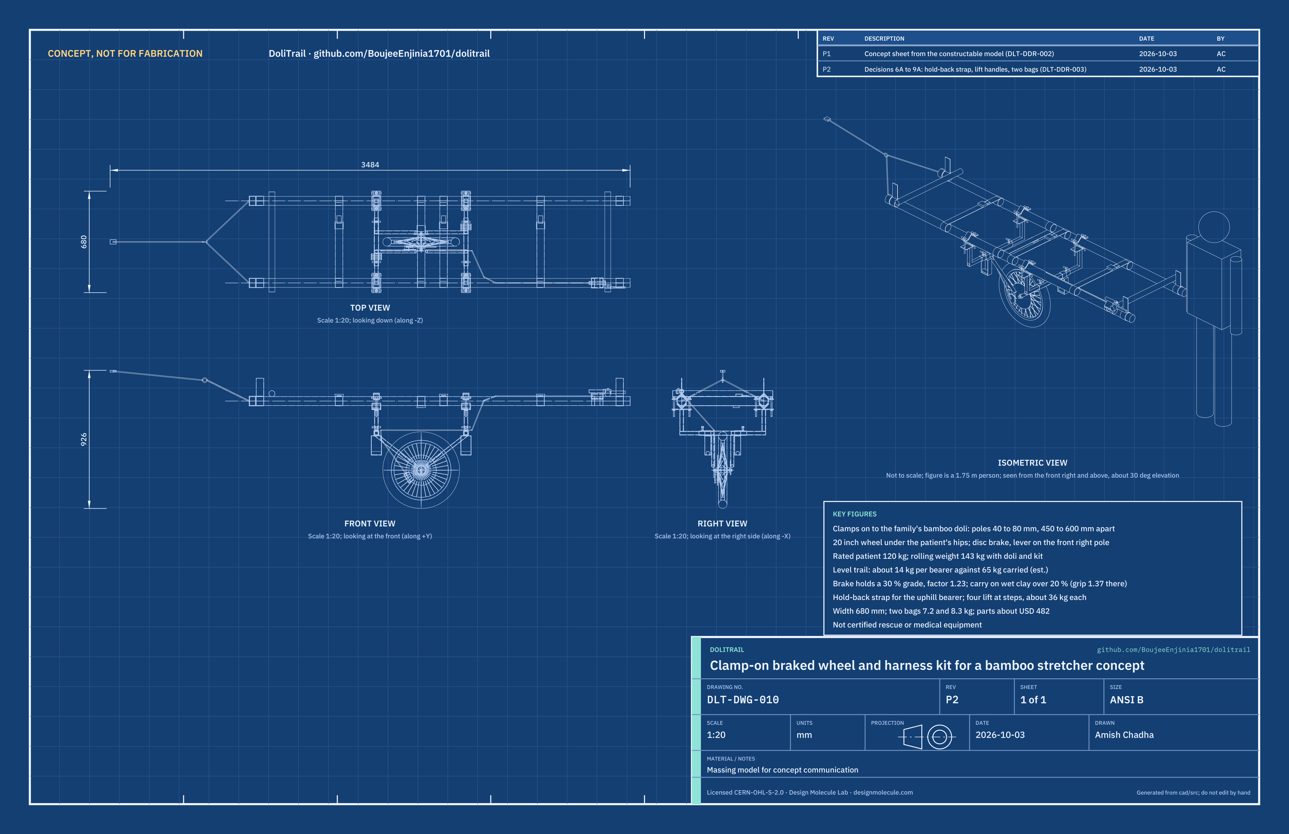
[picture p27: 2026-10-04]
media/concept-blueprint.png

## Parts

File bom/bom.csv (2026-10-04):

line | item | qty | spec | supplier | unit_cost_usd | make_buy | notes
1 | Fork unit | 1 | Welded steel: two 30 x 30 x 2 mm square tube stubs 320 mm long; four 22.2 x 1.6 mm round tube struts about 380 mm long; two 5 mm dropout plates with 10 mm slots open downward, the left one with the brake caliper lobe; four M8 nuts welded over 9 mm holes for the set screws; primed and painted | Local fabrication or cycle-rickshaw workshop | 62.00 | Make | Steel about USD 12, cutting, jig welding and paint about USD 50. IS 1161 YSt 210 tube or equal
2 | Side arm | 4 | 25 x 25 x 1.6 mm square tube spigot 230 mm long with a 145 mm post welded on top at its outer end; 60 x 130 x 4 mm saddle plate with a 3 mm steel V (90 deg, 60 mm wide inside); two M8 nuts welded under the plate ears at 52 mm either side of the V | Local fabrication | 15.00 | Make | Same jig for all four; arms are handed only by the side the post faces
3 | Upper jaw | 4 | 3 mm steel strip 40 mm wide bent to a 90 deg inverted V with two flat ears, 130 mm overall; two 9 mm holes at 104 mm centres | Local fabrication | 4.00 | Make | Bent in a vice over a 90 deg former
4 | Jaw liner | 8 | 5 mm rubber sheet (or cut truck inner tube, three layers) 60 x 66 mm for the saddles and 40 x 70 mm for the jaws, bent into the V and glued with contact adhesive | Tyre shop or rubber supplier | 1.50 | Make | Replace when worn through or loose
5 | T-handle bolt and set screw | 12 | Eight M8 x 130 mm T-handle clamp bolts with 25 mm washers (close the clamps); four M8 x 40 mm T-handle set screws (lock the arms in the stubs); zinc plated | Fastener or machinery supplier | 3.00 | Buy | No loose tools needed to fit the kit
6 | Wheel | 1 | 20 inch (ISO 406) cargo or tricycle wheel: double-wall rim, 36 spokes of 2.0 mm or heavier, steel front disc hub 100 mm over the locknuts with a solid 3/8 inch axle and nuts (not quick release); 20 x 2.125 (57-406) knobbly tyre and tube; wheel rated 200 kg and tyre 150 kg or more by the seller | Bicycle or cycle-rickshaw parts dealer | 55.00 | Buy | Rating to confirm when bought (DLT-DEC-001)
7 | Disc brake set | 1 | Cable-operated disc caliper with sintered pads and a post-mount adapter; 203 mm rotor with six bolts; brake lever for a 22.2 mm bar with a parking lock; 2.2 m of cable and housing | Bicycle parts dealer | 45.00 | Buy | Parking lock holds the lever on; adapter matched to the caliper lobe on the fork unit
8 | Lever mount | 1 | 22.2 x 1.6 mm tube stub 110 mm long welded on a 3 mm steel inverted V 80 mm long; 5 mm rubber liner; two 25 mm webbing straps with cam buckles round the pole | Local fabrication and tailor | 14.00 | Make | Fits poles of 40 to 80 mm; sits on top of the front right pole
9 | Cross strap | 1 | 50 mm polyester webbing, 1.6 m, with a 50 mm steel cam buckle; ends heat sealed | Webbing or tailoring supplier | 8.00 | Buy | Round both poles above the wheel and under the bed
10 | Patient strap | 3 | 50 mm polyester webbing, 1.8 m, with a 50 mm cam buckle and a red pull tab that frees it with one pull | Webbing or tailoring supplier | 9.00 | Buy | Chest, hips and legs
11 | Bearer harness | 2 | Sewn by a tailor: 50 mm webbing hip belt with a 25 mm foam pad, two padded shoulder straps and a chest strap, two adjustable slings ending in pole loops 110 mm across, four cam buckles | Local tailor | 35.00 | Make | One for the front bearer and one for the rear
12 | Wheel bag | 1 | Heavy canvas wheel bag about 700 x 340 x 560 mm with padded shoulder straps; takes the fork unit with the wheel and brake fitted, the lift handles and the pump kit (about 7.2 kg packed) | Local tailor or market | 25.00 | Buy | First of two bags (decision 8A). The wheel stays in the fork unit for carrying, which protects the spokes
13 | Fitting card | 1 | A4 card printed both sides with the fitting pictograms and the safety stops, laminated | Local printer | 3.00 | Buy | Kept in the bag pocket
14 | Hook-and-loop cable ties | 8 | 20 mm hook-and-loop ties, 200 mm long, to hold the brake housing to the frame and pole | Market | 0.50 | Buy | Reusable
15 | Pump and puncture kit | 1 | Mini hand pump with a Schrader head, two tyre levers, patches and glue, spare 20 inch tube | Bicycle parts dealer | 18.00 | Buy | Kept with the kit
16 | Hold-back strap | 1 | Sewn by a tailor: two closed end caps of 50 mm polyester webbing, 40 mm deep, that slip over the rear pole ends (40 to 80 mm poles, cinched by a 25 mm cam strap); two 25 mm webbing legs about 420 mm long to a 40 mm steel ring; a 600 mm tail with a cam buckle that clips to the rear bearer's hip belt | Local tailor | 6.00 | Make | Decision 7A. Price basis: about 2.5 m of webbing at USD 0.80 a metre, ring and buckle USD 2, sewing USD 2
17 | Lift handle | 2 | 50 mm polyester webbing band sewn shut round a cross stub (front stub left of centre, rear stub right), with a 130 mm hand loop and a 25 mm foam grip sleeve 60 mm long | Local tailor | 3.00 | Make | Decision 9A; stays on the fork unit. Price basis: 0.5 m of webbing USD 0.40, foam tube USD 0.60, sewing USD 2
18 | Parts bag | 1 | Canvas backpack about 45 L with padded straps and a pocket for the fitting card; takes the side arms, jaws, bolts, lever mount, straps, harnesses and hold-back strap (about 8.3 kg packed) | Local tailor or market | 15.00 | Buy | Second of two bags (decision 8A). Price basis: market canvas backpack USD 12 to 18

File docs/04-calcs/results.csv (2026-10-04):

tag | quantity | value | unit | note
G1 | Wheel diameter (20 x 2.125 tyre) | 514.000 | mm
G2 | Pole centres the clamps reach | 450 to 600 | mm
G3 | Pole diameters the clamps close on | 40 to 80 | mm
G4 | Tyre contact below the pole centres (60 mm pole) | 720.000 | mm
G5 | Width over clamps, reference doli (550 mm centres) | 680.000 | mm
G6 | Largest pole centres for a width of 700 mm | 570.000 | mm
G7 | Spigot inside its stub at 600 mm centres | 77.500 | mm
K1 | Mass, fork unit | 2.653 | kg
K2 | Mass, side arms | 3.273 | kg
K3 | Mass, upper jaws | 0.599 | kg
K4 | Mass, jaw liners | 0.212 | kg
K5 | Mass, t-handle bolts and set screws | 1.054 | kg
K6 | Mass, wheel | 2.600 | kg
K7 | Mass, disc brake set | 0.810 | kg
K8 | Mass, lever mount | 0.367 | kg
K9 | Mass, bearer harnesses | 1.500 | kg
K10 | Mass, straps, two bags, card, ties, pump and puncture kit | 2.060 | kg
K11 | Kit mass, everything in the two bags | 15.527 | kg
K12 | Kit mass fitted to the doli (frame, wheel, brake, straps, lift handles) | 12.517 | kg
K13 | Wheel bag: fork unit with lift handles, wheel, brake, pump kit and bag (decision 8A) | 7.213 | kg
K14 | Parts bag: arms, jaws, bolts, lever mount, straps, harnesses, hold-back strap and bag | 8.314 | kg
K15 | Mass, hold-back strap; lift handles (two) | 0.20; 0.20 | kg
L1 | Rolling weight: rated patient, doli and fitted kit | 142.517 | kg
L2 | Bearer loops ahead of and behind the wheel | 1330 and 1080 | mm
L3 | Carrying today: load per bearer, two bearers (four bearers) | 65.0 (32.5) | kg
L4 | Level trail: pitch balance on the heavier end (100 mm placement error) | 13.196 | kg
L5 | Level trail: average load per bearer with steadying allowance | 13.724 | kg
L6 | Reduction against carrying with two bearers (R4) | 78.886 | %
L7 | 30 % descent, brake on: downhill (front) bearer load | 45.570 | kg | estimate
L8 | Level trail: pull to keep rolling, shared by two bearers | 55.924 | N each | estimate
L9 | 15 % side slope: roll moment held by the bearers | 170.062 | N m
L10 | 15 % side slope: up and down force at each bearer's hands | 154.602 | N | about 16 kg
B1 | Along-slope force on a 30 % grade, rated load | 401.738 | N
B2 | Brake torque needed at the wheel | 103.247 | N m
B3 | Brake torque available, wet sintered pads, 203 mm rotor, lever locked | 126.700 | N m
B4 | Brake factor (available / needed) | 1.227
B5 | Wheel load normal to the slope (bearer share taken off) | 961.986 | N
B6 | Tyre grip factor on wet clay or mud (mu 0.35) | 0.838
B7 | Tyre grip factor on a wet test ramp (mu 0.60) | 1.437
B8 | Shortfall on wet mud, to be held back by the uphill bearer | 6.630 | kg-force
B9 | Tyre grip factor on wet clay at the 20 % carry limit (rolling allowed up to here) | 1.369
B10 | Hold-back strap pull, 30 % wet clay, wheel at the grip limit | 65.043 | N | the rule says carry here; shown for a patch met by surprise
B11 | Hold-back strap strength factor against the whole along-slope force on 30 % | 24.892 |  | two 25 mm legs; webbing strength to confirm
C1 | Slip resistance of one clamp along the pole (wet) | 1979.899 | N
C2 | Slip resistance of the two clamps on one pole | 3959.798 | N
C3 | Clamp factor against the 1.5 kN pull of R1, one pole | 2.640
C4 | Bamboo crush factor at the clamp force | 2.000 |  | to confirm on real poles
C5 | Vertical load on each saddle, rated load | 318.825 | N
C6 | Braking pull per clamp on a 30 % grade | 100.434 | N
S1 | Strut axial load, twice the rated load | 2512.538 | N
S2 | Strut stress, twice the rated load with the side load | 104.274 | MPa
S3 | Strut factor on yield at twice the rated load | 2.014
S4 | Strut buckling factor at twice the rated load | 30.839
S5 | Stub bending stress at the strut, twice the rated load | 68.601 | MPa
S6 | Spigot bending stress at the stub end, twice the rated load | 66.756 | MPa
S7 | Lowest structural factor on yield at twice the rated load | 2.014
S8 | Clamp bolt tension, each (two per clamp) | 1000.000 | N | M8 class 4.6 proof load about 8.4 kN
S9 | Wheel: seller's rating / twice the wheel load | 0.702
S10 | Tyre: rating / twice the wheel load | 0.526
S11 | Tyre: rating / the rated wheel load | 1.053
S12 | Wheel proof load before use, twice the rolling weight (decision 6A) | 285.033 | kg
W1 | Overall width with wheel, reference doli (R6) | 680.000 | mm
H1 | Rise of the poles at the wheel to clear a 400 mm step | 450.000 | mm
H2 | Pole height while the wheel clears the step | 1170.000 | mm
H3 | Lift per bearer, two bearers | 71.258 | kg
H4 | Lift per bearer, four bearers | 35.629 | kg
H5 | Pull on each lift handle, four lifting | 349.522 | N
H6 | Stub bending at the strut from a handle, twice the handle pull | 12.831 | MPa
H7 | Lift handle webbing strength factor (50 mm) | 28.610
T1 | Fitting time, two people (estimate) | 4.667 | min
Q1 | Estimated cost of the constructable design | 482.000 | USD
Q2 | Against the value-engineering target of USD 1,500 | -1018.000 | USD | negative = under
Q3 | Cross strap above the tyre | 174.000 | mm

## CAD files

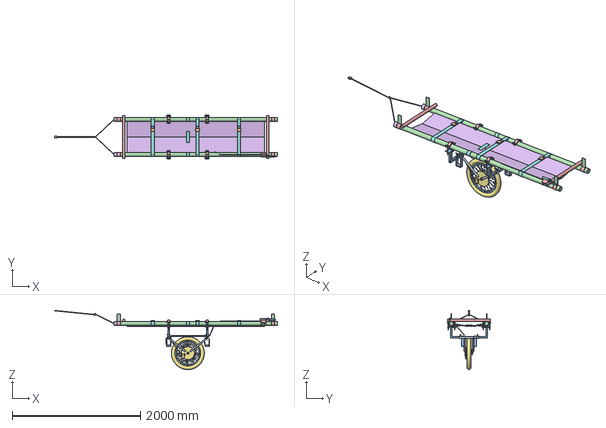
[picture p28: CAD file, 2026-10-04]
cad/step/dolitrail-assembly.step
3484.0 x 680.0 x 925.9 mm

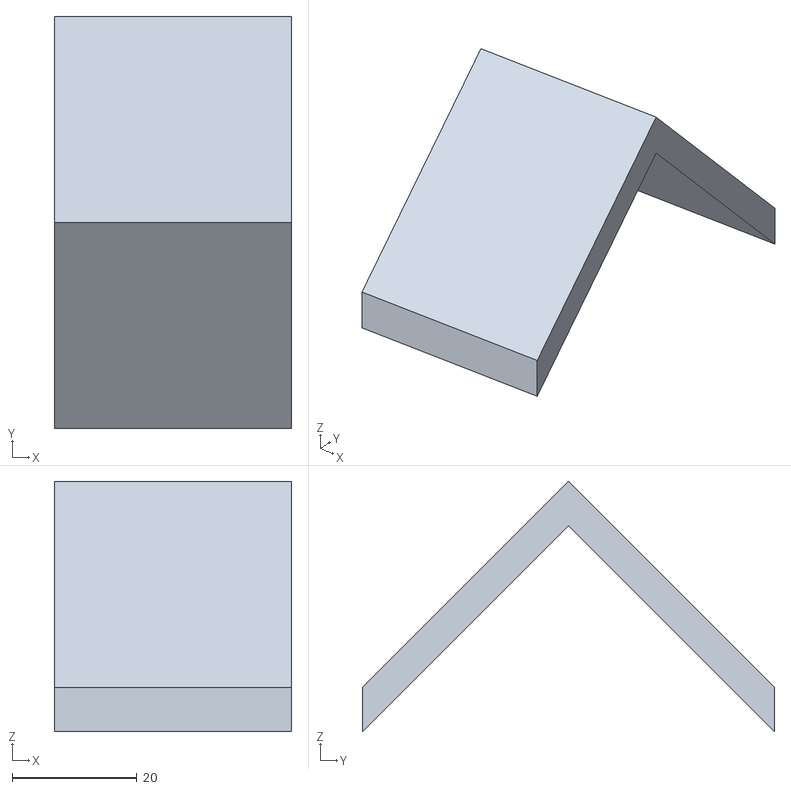
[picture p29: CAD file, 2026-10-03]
cad/stl/jaw-liner-upper.stl
38.0 x 66.0 x 40.1

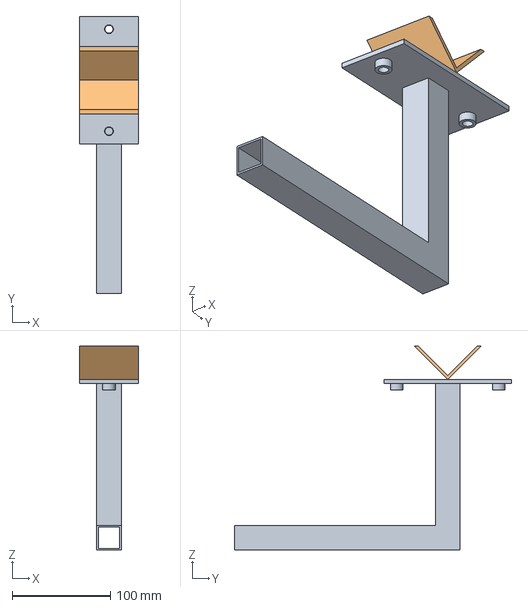
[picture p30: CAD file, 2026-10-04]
cad/step/side-arm.step
60.0 x 282.5 x 208.0 mm

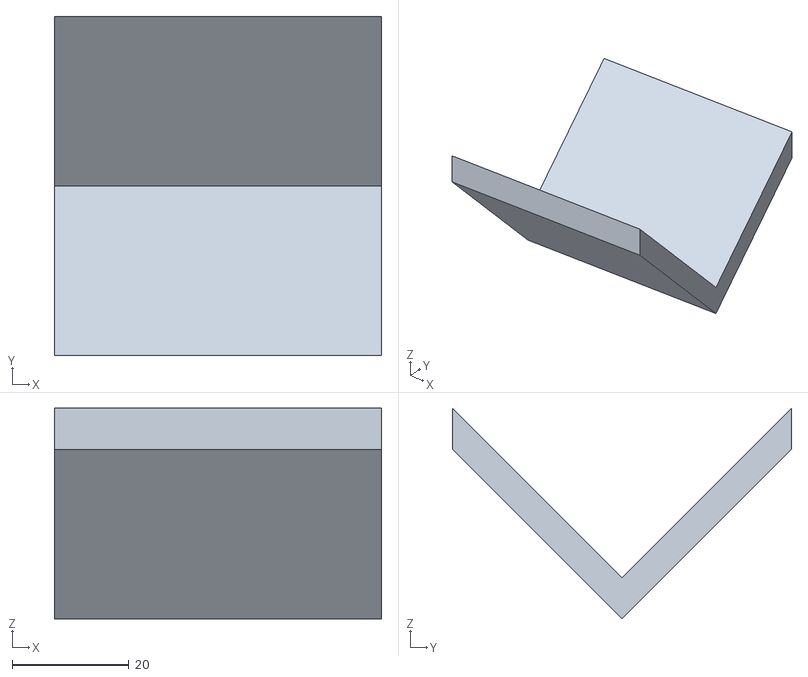
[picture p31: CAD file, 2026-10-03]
cad/stl/jaw-liner-lower.stl
56.0 x 58.0 x 36.1

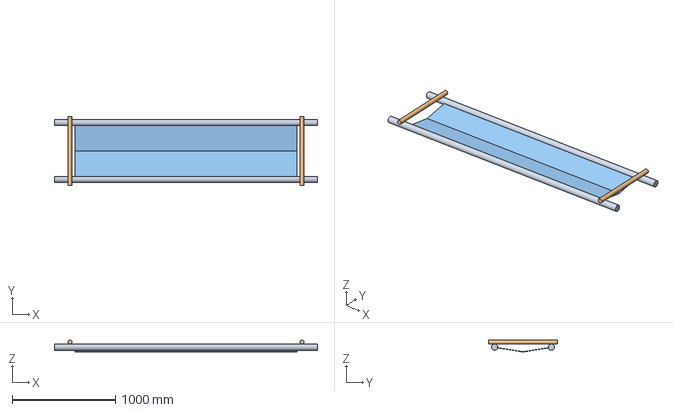
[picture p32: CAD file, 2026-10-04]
cad/step/reference-doli-context.step
2550.0 x 670.0 x 117.0 mm

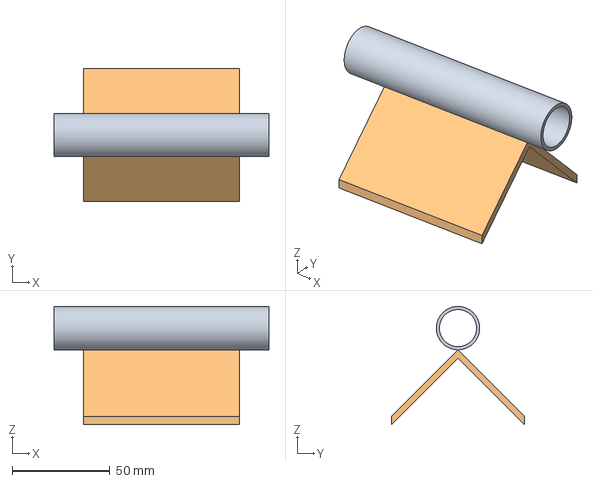
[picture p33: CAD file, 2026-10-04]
cad/step/lever-mount.step
110.0 x 68.0 x 60.4 mm

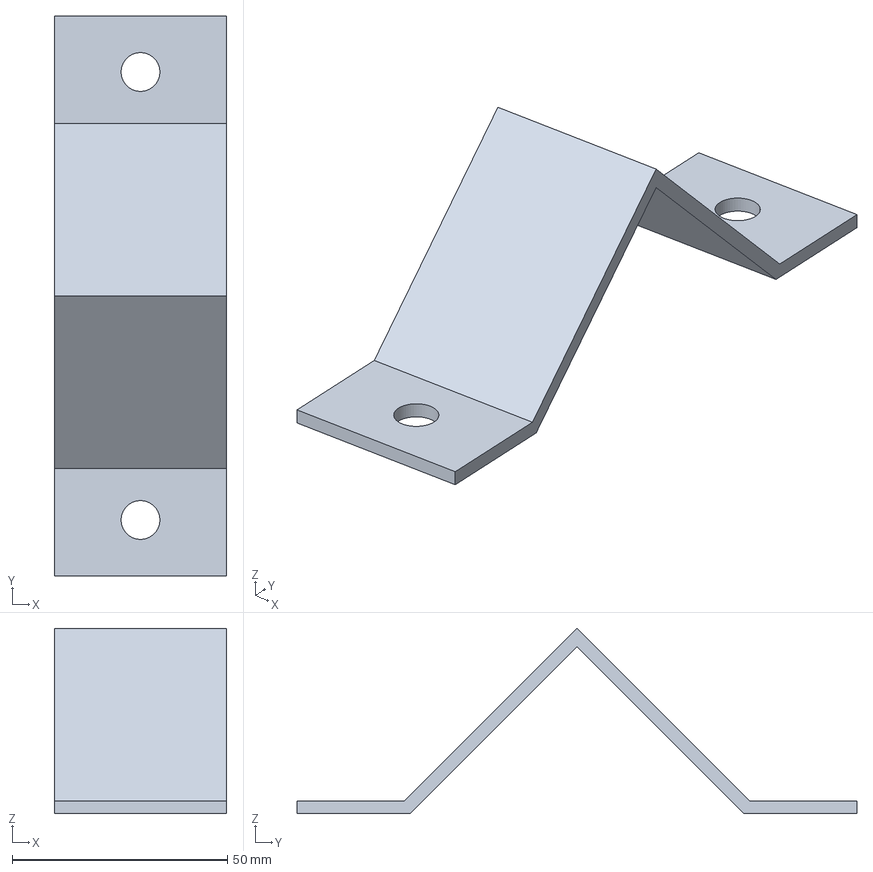
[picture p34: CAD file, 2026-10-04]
cad/step/upper-jaw.step
40.0 x 130.0 x 43.0 mm

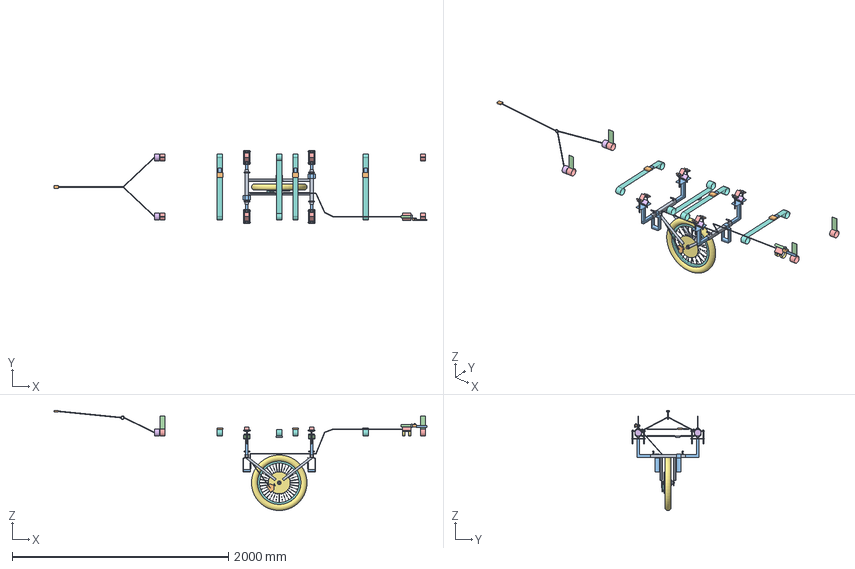
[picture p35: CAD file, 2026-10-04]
cad/step/dolitrail-kit.step
3451.0 x 680.0 x 925.9 mm

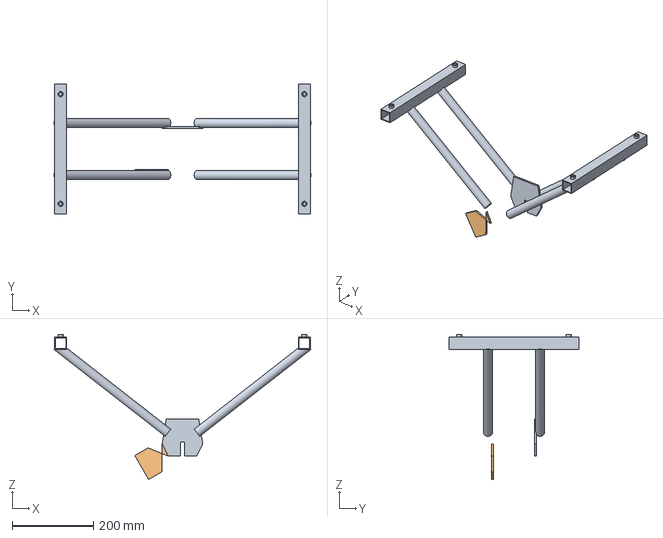
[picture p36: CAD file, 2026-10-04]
cad/step/fork-unit.step
632.6 x 320.0 x 356.9 mm

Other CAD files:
cad/stl/lever-mount.stl
cad/stl/side-arm.stl
cad/stl/upper-jaw.stl

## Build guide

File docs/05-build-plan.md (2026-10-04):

---
doc_id: DLT-BLD-001
title: DoliTrail prototype build plan
project: DoliTrail
doc_type: Build plan
version: "0.2"
status: Draft
date: '2026-10-03'
author: Amish Chadha
license: CERN-OHL-S-2.0
revisions:
- version: "0.1"
  date: '2026-10-03'
  author: Amish Chadha
  change: First build plan; design made constructable (DLT-DDR-002)
- version: "0.2"
  date: '2026-10-03'
  author: Amish Chadha
  change: "Amish's decisions 6A to 9A (DLT-DDR-003): hold-back strap (3.12), lift handles (3.13), two bags (3.11), wheel proof load before use, four lifters at steps; overview, step 9, joints 9 and 10 and sketches DLT-DWG-107 and 108 added or redrawn"
---

# DoliTrail prototype build plan

**Plan, not yet built.** How to make the first DoliTrail kit and fit it to a doli, component by component. Building and testing to it is TRL 4 work. Decisions are kept in the design decisions register (`docs/06-design-decisions.md`), not here.

> **Safety:** DoliTrail will carry a person over steep, wet ground. It is an open engineering reference, not certified medical or rescue equipment. The first kit carries sandbags, never a patient, until the proof loads and the wet ramp test in sections 5 and 6 have passed. Welding, grinding and cutting need eye, hand and hearing protection and a clear, ventilated space.

## 1. What you are building

Every component, pulled apart and numbered in build order

*Figure 1. The kit in build order. One harness is shown laid flat; the lift handles are sewn on the fork unit's stubs.*

The kit turns a family's bamboo doli into a wheeled stretcher with a brake. A welded steel fork unit holds a 20 inch wheel; four side arms slide into its two cross stubs and end in rubber-lined V saddles that the bamboo poles sit in, each closed by an upper jaw and two T-handle bolts. A disc brake on the wheel is worked from a lever strapped to the front right pole. A cross strap keeps the bed off the tyre, three patient straps hold the patient, and two harnesses take the pole ends in slings at each bearer's knuckle height. A hold-back strap ties the rear bearer's hip belt to the rear pole ends for descents, and two webbing lift handles sewn round the cross stubs let two helpers lift at steps. The kit walks in with the two bearers in two bags. Eight components are made (the fork unit, side arms, upper jaws, liners, lever mount, harnesses, hold-back strap and lift handles) by cutting, bending, drilling, welding, gluing and sewing; the rest are bought bicycle parts, fasteners, webbing and bags. Parts cost about USD 482. The sizes are for the reference doli: two 60 mm bamboo poles at 550 mm centres; the kit adjusts to poles of 40 to 80 mm at 450 to 600 mm centres.

## 2. What changed to make it buildable

*Table 1. Changes from the concept.*

| Component | The concept had | The buildable design has | Why |
| --- | --- | --- | --- |
| Wheel and fork | "A single wheel in a fork under the middle" | A welded fork unit with two cross stubs fore and aft of the wheel, four struts and dropout plates | The stubs pass below the bed and clear of the wheel; the struts form a stiff truss |
| Pole clamps | "Adjustable clamps with rubber jaws" | Four side arms that slide in the stubs, each with a rubber-lined V saddle, an upper jaw and two T-handle bolts | Fits poles of 40 to 80 mm at 450 to 600 mm centres, by hand |
| Cross frame and strap | One frame and a strap | The fork unit and arms are the frame; the strap is a webbing loop round both poles above the wheel | Keeps the bed 174 mm above the tyre |
| Brake | "Cable or rod brake" | Disc brake with the caliper on a lobe of the left dropout plate | Works wet; the mount is part of the welded plate |
| Lever | "At the front bearer's hand" | A rubber-lined lever mount strapped on the front right pole | A bicycle lever needs a 22.2 mm bar |
| Harness | "Pole-end cups" | Pole loops on adjustable slings | Fits every pole end and bearer |
| Wheel fixing | Not stated | Solid axle and nuts in slots open downward | Nothing to open by mistake |
| Bed | Not considered | Clamps on bare pole; the bed's lashing is slid aside at the four clamp points | The inboard bolt passes beside the pole |
| Descents on wet ground | Brake only | A hold-back strap: webbing caps over the rear pole ends, legs to a ring, a tail to the rear bearer's hip belt | The tyre can slide on wet clay before the brake slips; the uphill bearer holds the doli back |
| Steps | Two bearers lift | Two webbing lift handles sewn round the cross stubs for two helpers | Four people share the lift, about 36 kg each |
| Carrying the kit | One bag | Two bags, one per bearer: about 7.2 and 8.3 kg | Each load stays under 10 kg |

Cut across the doli through the front clamps

*Figure 2. Cut across the doli through the front clamps: the poles sit in the saddles, the wheel runs between the stubs.*

## 3. Making the components

Make and paint the steel parts in the workshop, glue in the liners and sew the harnesses before the kit goes anywhere near a doli.

### 3.1 Fork unit

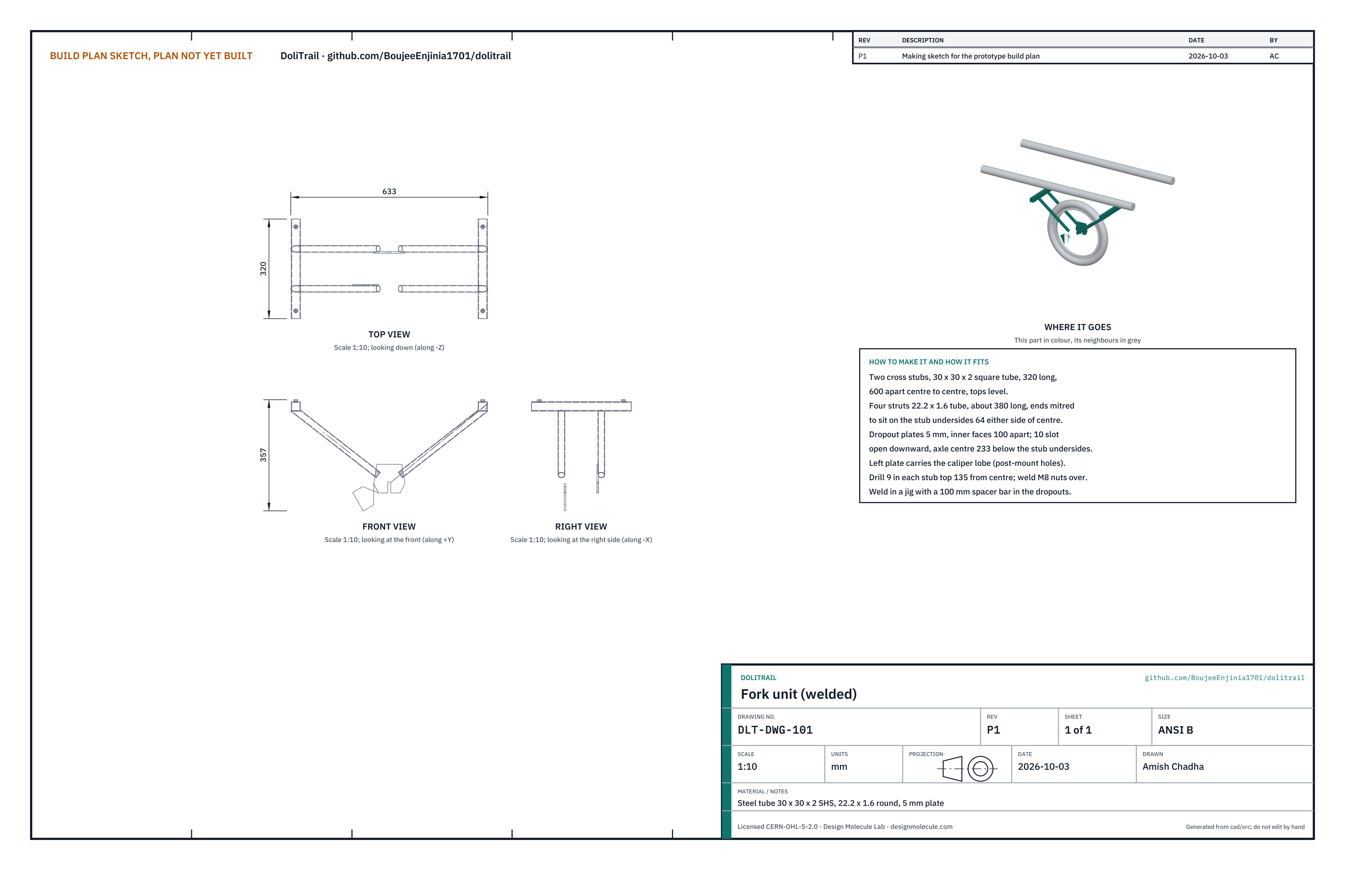
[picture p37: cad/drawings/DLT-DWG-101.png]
Making sketch: fork unit


**What it is and what it is made from.** The backbone of the kit: two cross stubs of 30 x 30 x 2 mm square steel tube, 320 mm long, joined by four struts of 22.2 x 1.6 mm round tube to two 5 mm steel dropout plates that hold the wheel axle. The left plate has a lobe that carries the brake caliper. Mild steel tube and plate, welded and painted.

**How to make it.**

1. Cut the two stubs 320 mm long, square ends. Drill a 9 mm hole in the top face of each, 135 mm either side of the centre, and weld an M8 nut over each hole.
2. Cut the two dropout plates from 5 mm plate to the outline on the sketch: a slot 10 mm wide running up from the bottom edge, with the axle centre at its top. Add the caliper lobe to the left plate and drill it for the caliper adapter.
3. Set the stubs in a jig, parallel, 600 mm apart centre to centre and level. Set the plates on a 3/8 inch spacer bar with a 100 mm spacer between them, the axle centre 233 mm below the stub undersides and midway between the stubs.
4. Cut the four struts about 380 mm long and mitre both ends so they sit flat on the stub underside and on the outer face of the plate, with their centre lines 64 mm either side of the middle.
5. Tack, check the dropouts are square to the stubs and 100 mm apart, then weld fully. Grind the slot clean, prime and paint.

**How it fits the parts next to it.**

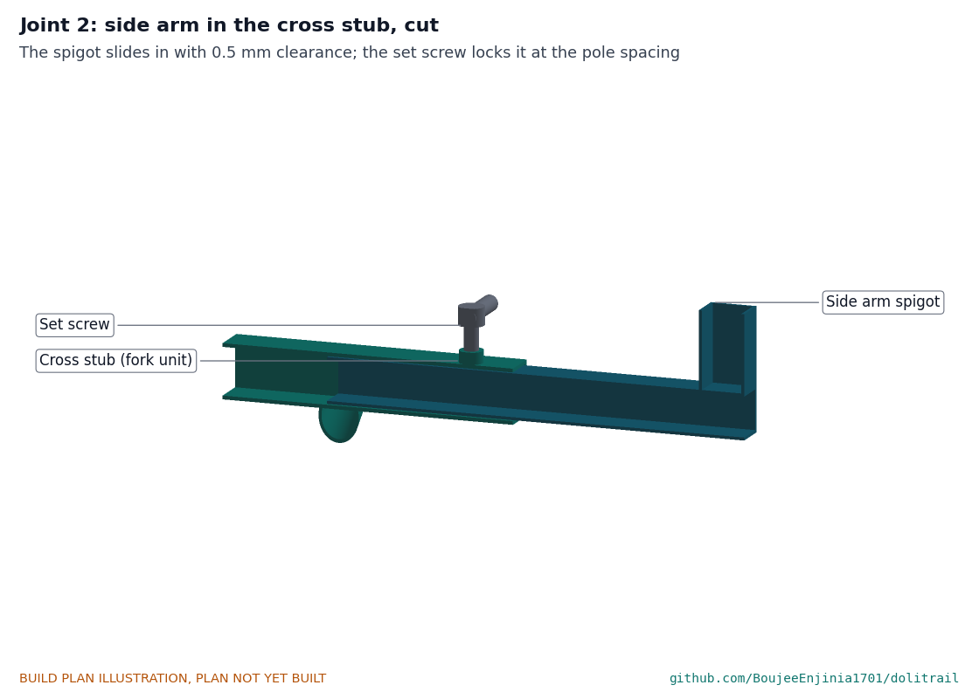
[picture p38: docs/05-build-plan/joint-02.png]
Close-up: side arm in the cross stub


*Figure 3. A side arm's spigot in a cross stub, cut. The set screw locks it.*

The side arms' spigots slide into the stub ends with about 0.5 mm clearance each side; a T-handle set screw through each welded nut presses down on the spigot. The wheel axle drops up into the slots (Figure 5), and the caliper bolts to the inside of the lobe (Figure 6).

**Check before moving on.** A 3/8 inch rod slides through both slots square to the stubs; a stub offcut of the arm tube slides in each stub end by hand without rocking; no weld spatter in the stub bores.

### 3.2 Side arms

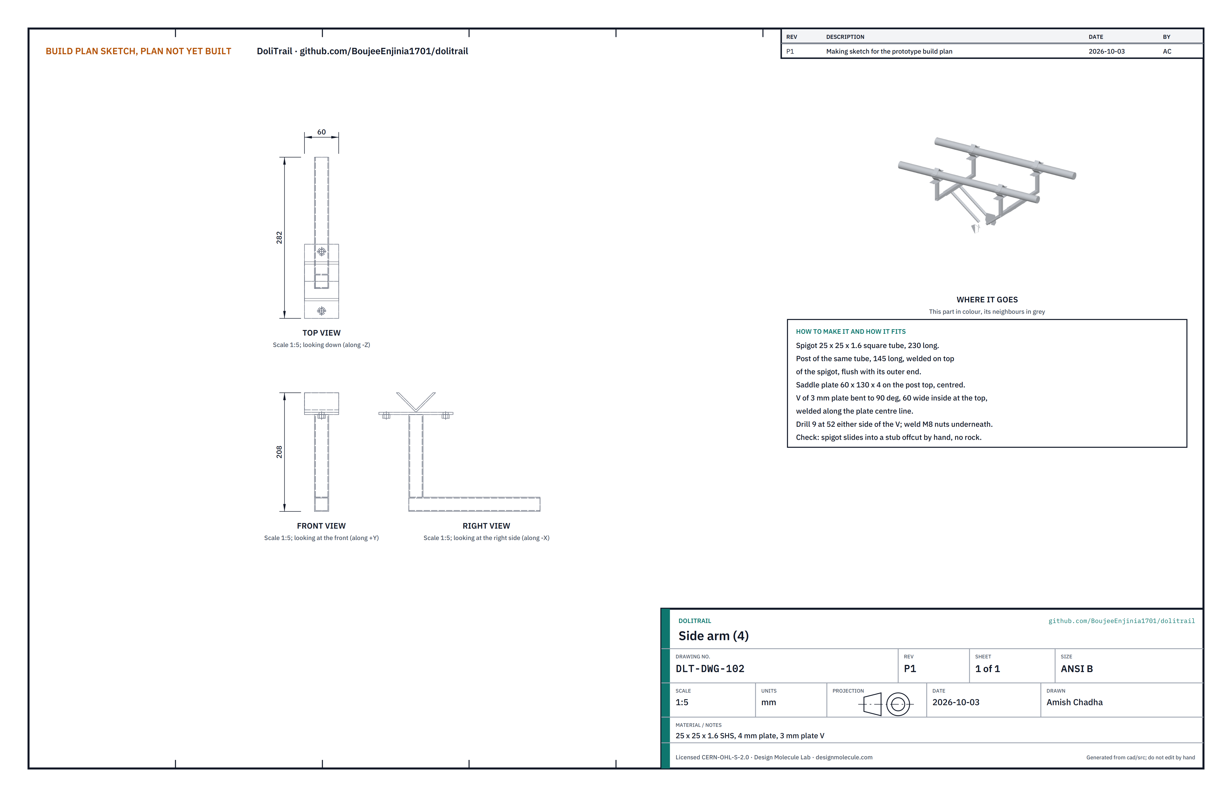
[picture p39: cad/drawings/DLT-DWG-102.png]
Making sketch: side arm


**What it is and what it is made from.** Four L-shaped arms of 25 x 25 x 1.6 mm square tube. Each has a 230 mm spigot that slides into a stub, a 145 mm post welded on top at its outer end, and a 60 x 130 x 4 mm saddle plate on the post carrying a 90 deg V of 3 mm plate, 60 mm wide inside. Two M8 nuts are welded under the plate ears.

**How to make it.**

1. Cut four spigots 230 mm and four posts 145 mm from the square tube.
2. Weld each post on top of its spigot, flush with the outer end, square in both directions (use the same jig for all four).
3. Cut the saddle plates 60 x 130 mm; drill two 9 mm holes 52 mm either side of the centre line; weld M8 nuts underneath.
4. Bend 3 mm plate 60 mm wide into a 90 deg V with 30 mm legs, and weld it along the plate centre line, the V running along the pole.
5. Weld the plate on top of the post, the V centred over it and running square across the spigot, so the pole lies along the doli. Grind, prime and paint.

**How it fits the parts next to it.**

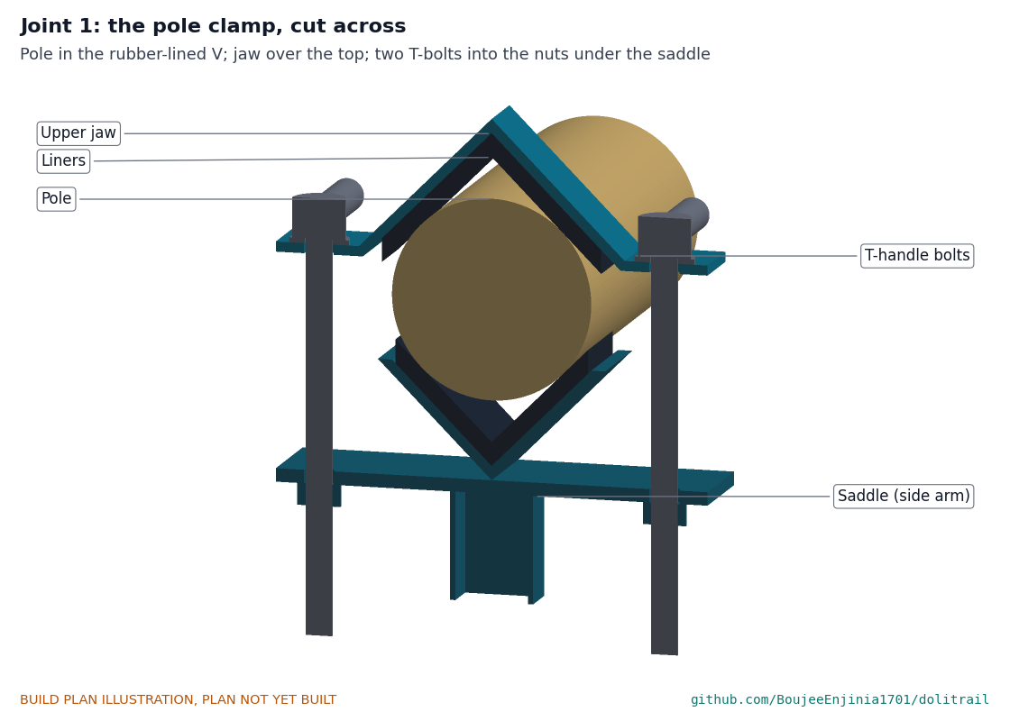
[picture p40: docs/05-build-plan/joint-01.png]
Close-up: the pole clamp, cut across


*Figure 4. A pole clamp, cut across: the pole in the rubber-lined V, the upper jaw over it, two T-bolts into the nuts under the saddle.*

The bamboo pole lies in the V on its rubber liner; the upper jaw closes over it and the two T-handle bolts pass through the jaw's ears into the nuts under the saddle plate.

**Check before moving on.** Every arm slides into every stub end; the V is square to the spigot; a 60 mm pipe sits in the V touching both faces.

### 3.3 Upper jaws

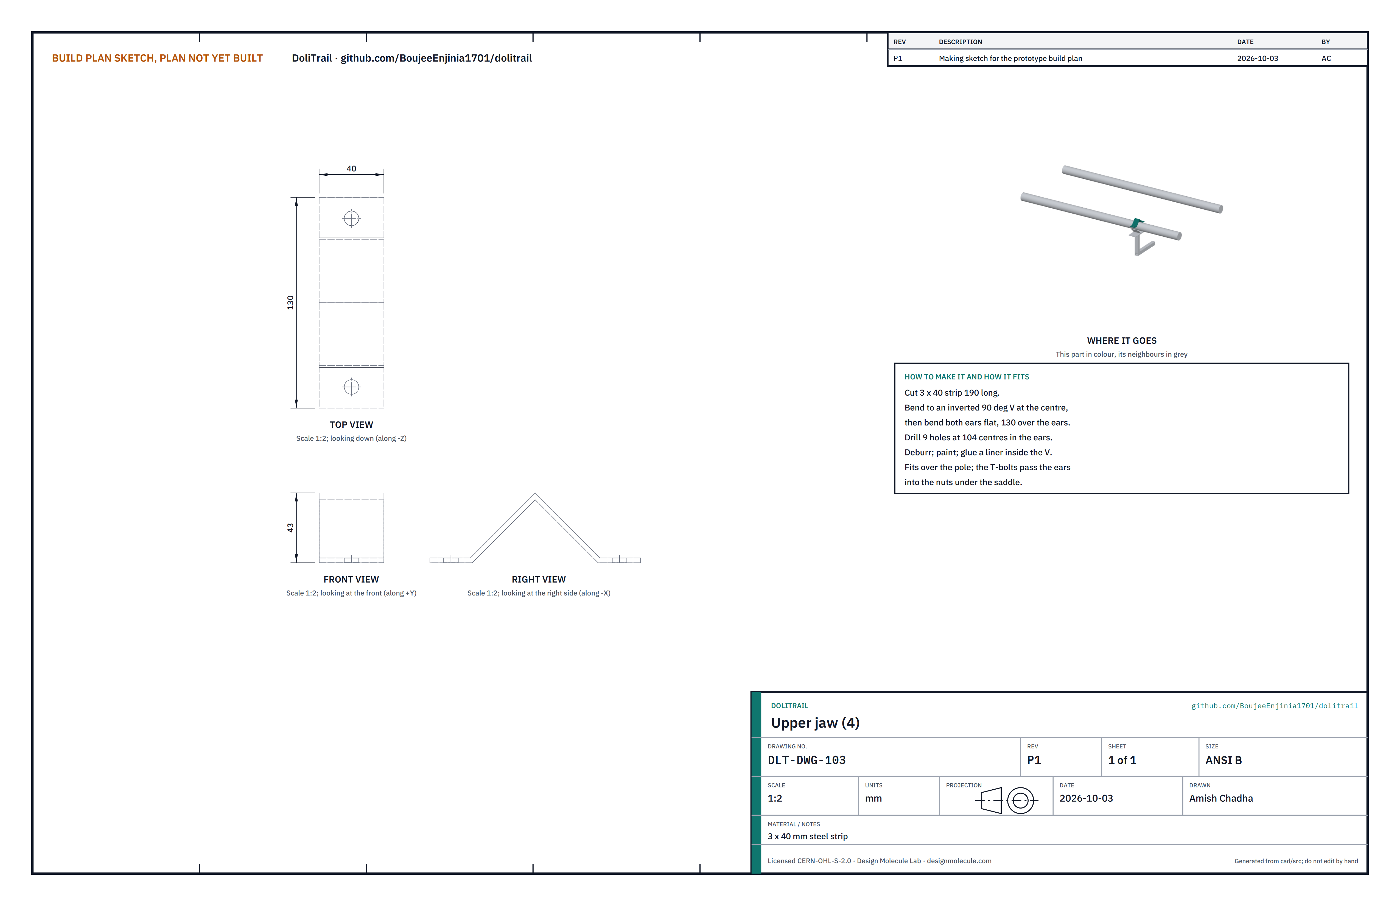
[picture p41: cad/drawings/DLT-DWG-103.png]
Making sketch: upper jaw


**What it is and what it is made from.** Four strips of 3 x 40 mm steel, 190 mm long, bent into an inverted 90 deg V with two flat ears, 130 mm over the ears.

**How to make it.**

1. Cut the strips 190 mm long.
2. Bend at the centre to 90 deg over a former in a vice; then bend each leg flat to make the ears, so both ears lie level.
3. Drill 9 mm holes in the ears at 104 mm centres. Deburr and paint.

**How it fits the parts next to it.** The jaw sits over the pole on its own liner; its ears take the T-handle bolts (Figure 4). On a 40 mm pole the ears come down to about 28 mm above the saddle ears; on an 80 mm pole they rise about 28 mm.

**Check before moving on.** The jaw's holes line up with the saddle nuts when it sits over a 60 mm pipe in the saddle.

### 3.4 Jaw liners

Making sketch: jaw liners

**What it is and what it is made from.** Eight pads of 5 mm rubber sheet, or three layers of truck inner tube glued together: 56 x 84 mm for the saddles and 38 x 94 mm for the jaws.

**How to make it.**

1. Cut the pads with a sharp knife against a straightedge.
2. Fold each along its centre line.
3. Coat the pad and the inside of the V with contact adhesive, wait ten minutes, press in and roll flat.

**How it fits the parts next to it.** The liner covers both faces of the V and stops short of the bolt holes. The pole bears only on rubber.

**Check before moving on.** No loose edges; the pad cannot be peeled by hand.

### 3.5 T-handle bolts and set screws (bought)

Buy eight M8 x 130 mm T-handle bolts with 25 mm washers for the clamps, and four M8 x 40 mm T-handle set screws for the arms, zinc plated. Run each into its welded nut once to clean the thread.

### 3.6 Wheel (bought)

Buy a 20 inch (ISO 406) cargo or tricycle wheel with a double-wall rim, 36 spokes of 2.0 mm or heavier and a steel front disc hub 100 mm over the locknuts, with a solid 3/8 inch axle and nuts (not quick release). Fit a 20 x 2.125 knobbly tyre and tube. Bolt the 203 mm rotor to the hub on the left side. Check the seller's ratings against the design decisions register.

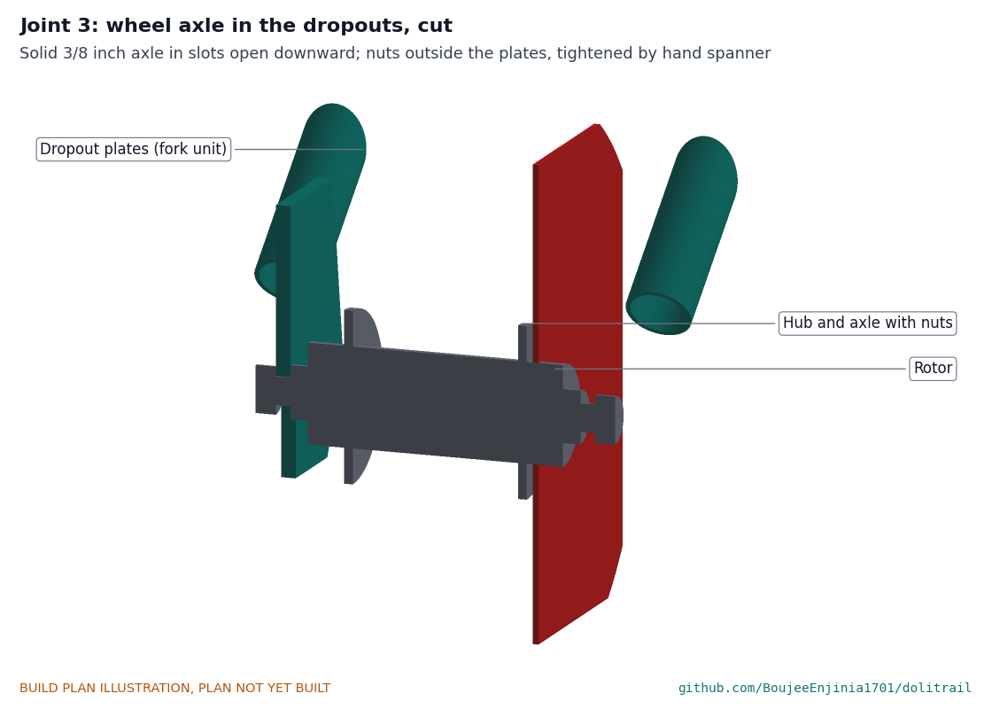
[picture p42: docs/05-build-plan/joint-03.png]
Close-up: wheel axle in the dropouts, cut


*Figure 5. The axle in the dropout slots, cut: nuts outside the plates.*

### 3.7 Disc brake set (bought)

Buy a cable-operated disc caliper with sintered pads and a post-mount adapter, a 203 mm six-bolt rotor, a brake lever for a 22.2 mm bar with a parking lock, and 2.2 m of cable and housing. Fit the adapter to the caliper lobe of the left dropout plate.

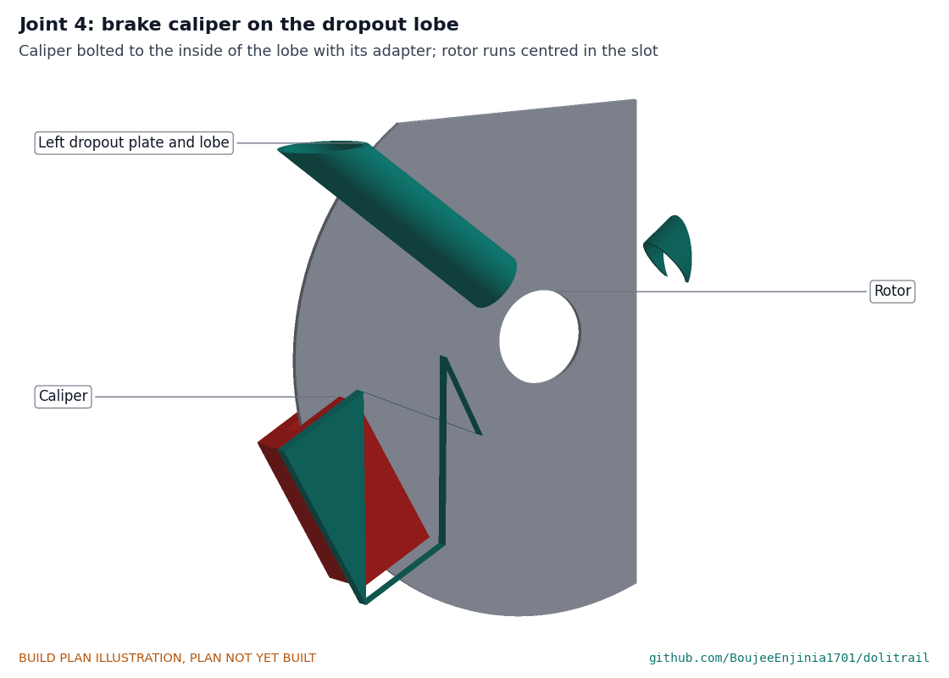
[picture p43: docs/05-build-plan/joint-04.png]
Close-up: brake caliper on the lobe


*Figure 6. The caliper bolted to the lobe, the rotor running in its slot.*

### 3.8 Lever mount

Making sketch: lever mount

**What it is and what it is made from.** A 110 mm stub of 22.2 x 1.6 mm tube, welded along the apex of an 80 mm long inverted V of 3 mm plate, with a 5 mm rubber liner inside the V and two 25 mm webbing cam straps.

**How to make it.**

1. Bend 3 mm plate 80 mm wide into a 90 deg V, 68 mm across the open side.
2. Weld the tube stub along the outside of the apex, centred, ends square. Paint.
3. Glue a rubber liner inside the V.
4. Sew two 25 mm webbing straps with cam buckles to pass round the pole, 28 mm either side of the centre.

**How it fits the parts next to it.**

Close-up: lever mount on the front right pole

*Figure 7. The lever mount on top of the front right pole, strapped round it; the brake lever clamps on the bar beyond the V.*

**Check before moving on.** On a 60 mm pipe, strapped tight, the mount does not turn when the lever is pulled hard.

### 3.9 Cross strap and patient straps (bought)

Buy 50 mm polyester webbing: one cross strap of 1.6 m with a cam buckle, and three patient straps of 1.8 m with cam buckles and a red pull tab. Heat-seal every cut end.

Close-up: cross strap round both poles

*Figure 8. The cross strap round both poles above the wheel, under the bed.*

Close-up: patient strap and quick-release buckle

*Figure 9. A patient strap round both poles; one pull on the tab frees it.*

### 3.10 Bearer harnesses

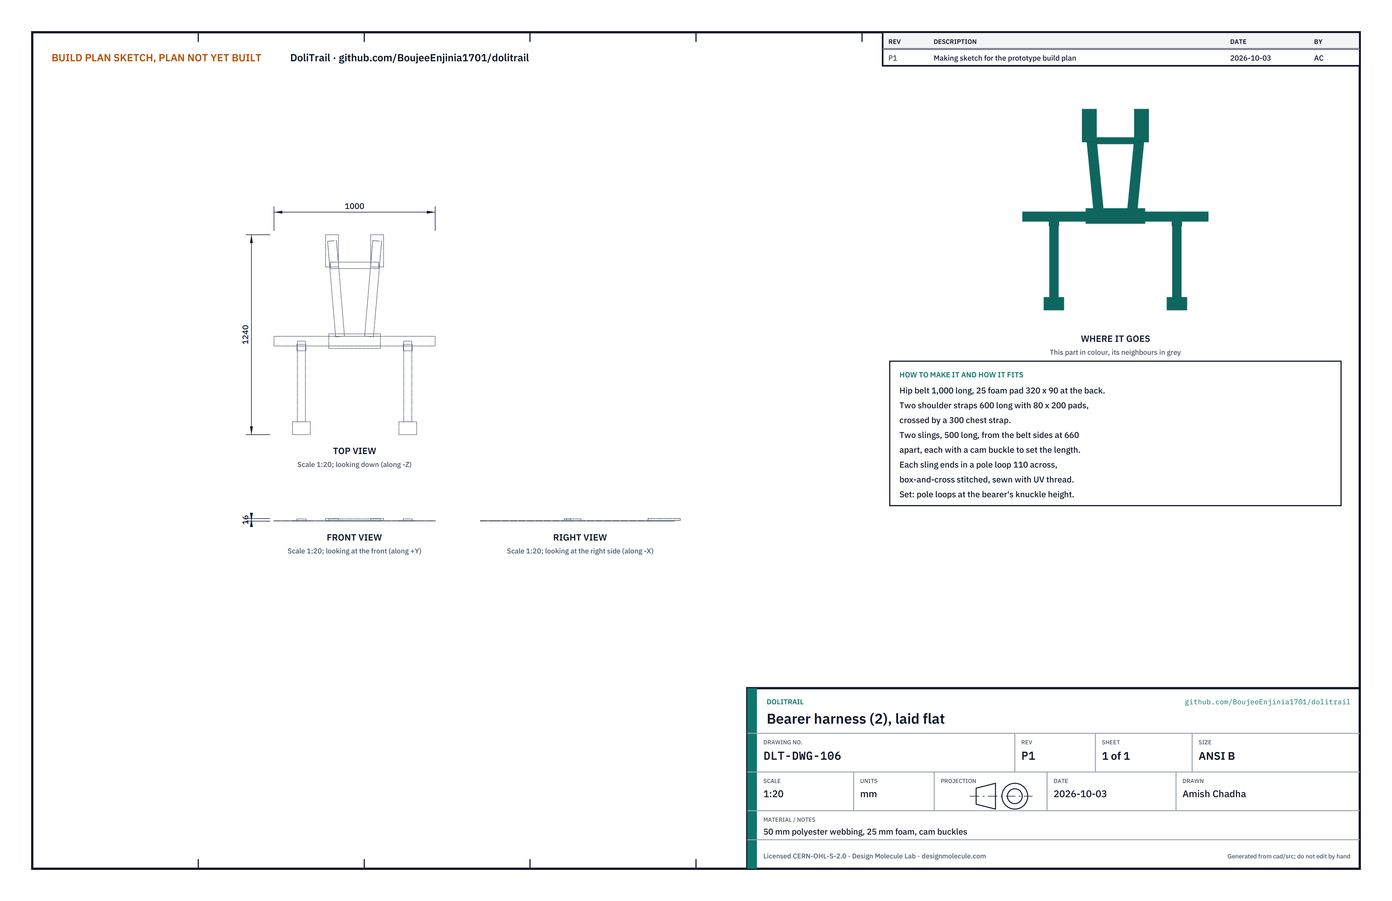
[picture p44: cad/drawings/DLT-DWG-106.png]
Making sketch: bearer harness


**What it is and what it is made from.** Two harnesses sewn by a tailor from 50 mm polyester webbing: a 1,000 mm hip belt with a foam pad, two padded shoulder straps joined by a chest strap, and two slings, each ending in a pole loop about 110 mm across, with cam buckles to set the length.

**How to make it.**

1. Cut and heat-seal the webbing: belt 1,000 mm, shoulder straps 600 mm, chest strap 300 mm, slings 500 mm, loops 400 mm.
2. Sew the shoulder straps to the belt at the back, 180 mm apart, crossing to the front; add the pads and the chest strap.
3. Sew a sling to each side of the belt, 660 mm apart; fit a cam buckle in each sling.
4. Fold each loop and box-and-cross stitch it to its sling with UV-resistant thread.

**How it fits the parts next to it.**

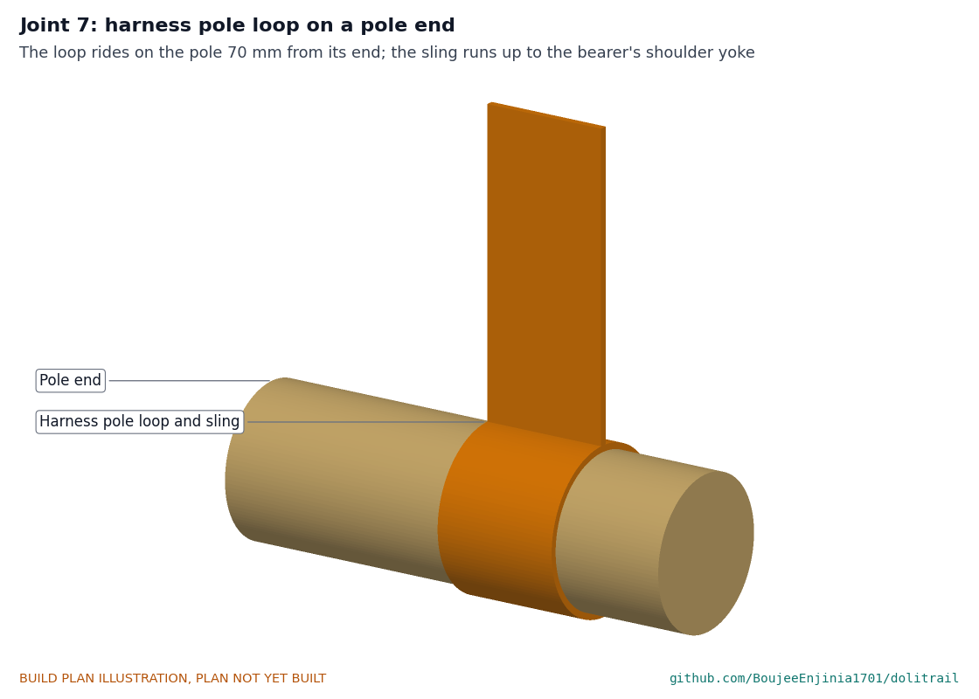
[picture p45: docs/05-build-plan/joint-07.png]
Close-up: harness pole loop on a pole end


*Figure 10. A harness pole loop on a pole end; the sling runs up to the bearer's yoke.*

**Check before moving on.** Hang 50 kg from each loop for one minute: no stitch pulls.

### 3.11 Two carry bags, fitting card, ties and pump (bought)

Two bags, one for each bearer. A canvas wheel bag about 700 x 340 x 560 mm with shoulder straps takes the fork unit with the wheel, brake and lift handles, and the pump kit: about 7.2 kg packed. A canvas backpack of about 45 litres takes the side arms, jaws, bolts, lever mount, straps, harnesses, hold-back strap and the fitting card: about 8.3 kg packed. Also buy an A4 laminated fitting card with the pictures of section 4 and the safety stops; eight hook-and-loop ties; a mini pump, tyre levers, patches and a spare tube.

### 3.12 Hold-back strap

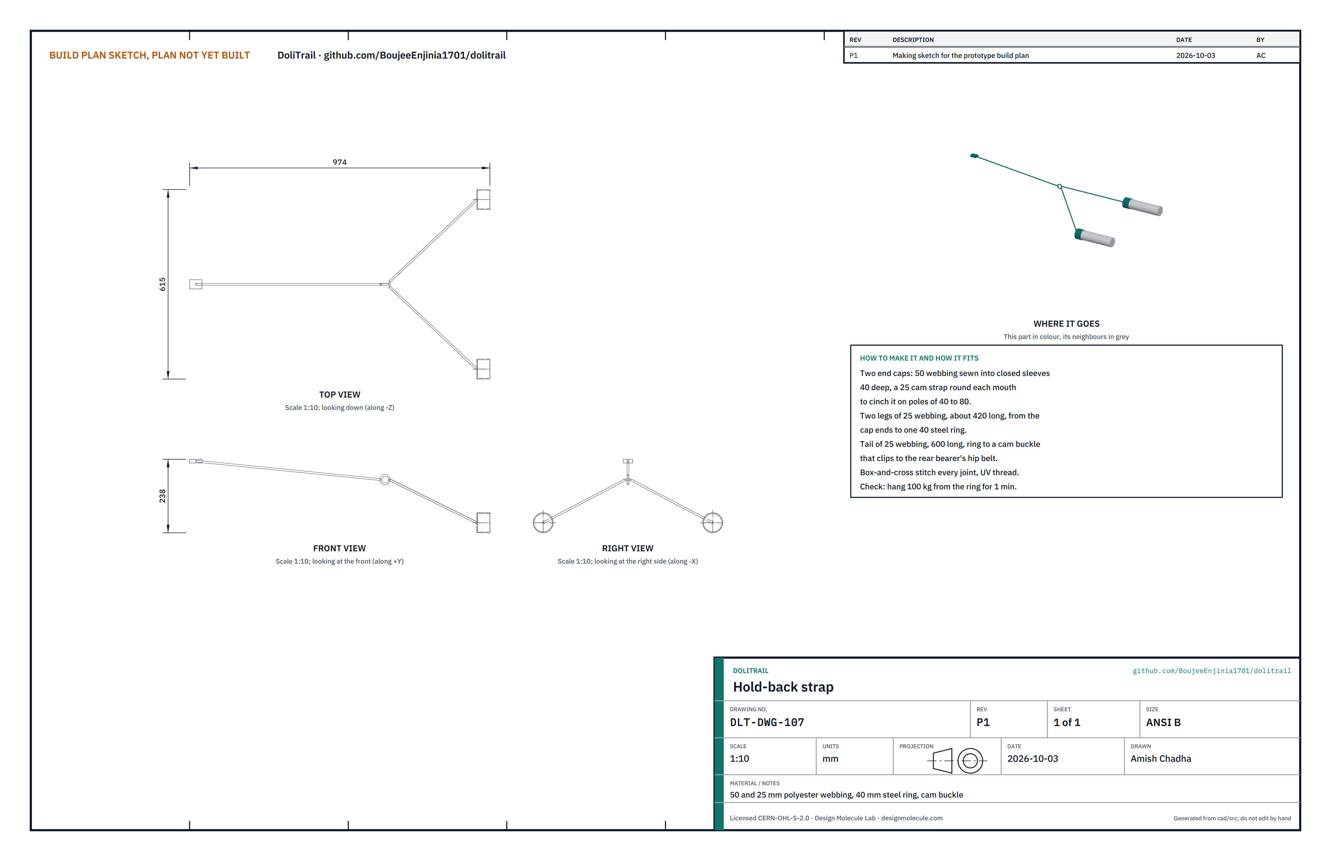
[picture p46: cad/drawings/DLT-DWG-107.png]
Making sketch: hold-back strap


**What it is and what it is made from.** A Y-shaped strap sewn by a tailor that lets the rear (uphill) bearer hold the doli back on a wet descent. Two closed end caps of 50 mm polyester webbing, 40 mm deep, slip over the rear pole ends, each with a 25 mm cam strap round its mouth; two 25 mm webbing legs, about 420 mm long, run from the caps to a 40 mm steel ring; a 600 mm tail runs from the ring to a cam buckle that clips to the rear bearer's hip belt.

**How to make it.**

1. Cut and heat-seal the webbing: two cap pieces of 50 mm webbing 300 mm long, two legs and a tail of 25 mm webbing.
2. Sew each cap into a closed sleeve that fits over an 80 mm pole end, and sew a 25 mm cam strap round its mouth so it cinches down onto a 40 mm pole.
3. Sew one end of each leg to the closed end of a cap, and the other end round the ring. Sew the tail round the ring and fit the cam buckle on its free end.
4. Box-and-cross stitch every joint with UV-resistant thread.

**How it fits the parts next to it.**

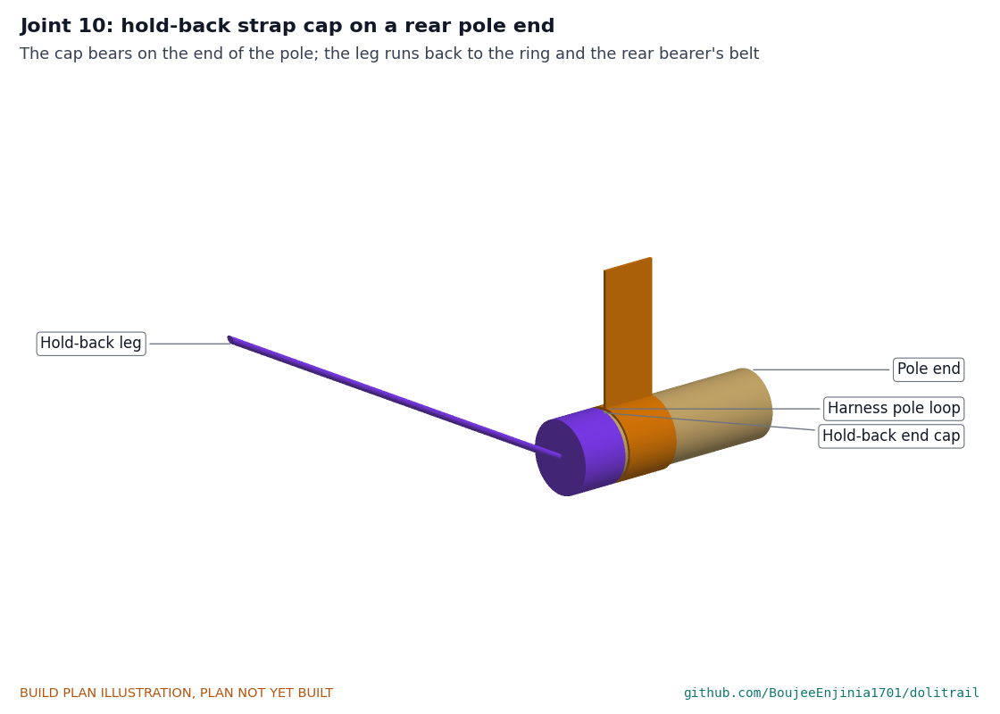
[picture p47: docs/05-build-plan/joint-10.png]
Close-up: hold-back strap cap on a rear pole end


*Figure 11. A hold-back cap on a rear pole end, just behind the harness pole loop.*

Each cap goes over a rear pole end, cinched tight, so the pull bears on the end of the pole and the cap cannot slide off backward. It sits about 5 mm behind the harness pole loop. The tail clips to the rear bearer's hip belt and is set so the bearer leans back slightly against it.

**Check before moving on.** Hang 100 kg from the ring for one minute, with both caps on a length of 60 mm pole: no stitch pulls and neither cap moves.

### 3.13 Lift handles

Making sketch: lift handle

**What it is and what it is made from.** Two handles of 50 mm polyester webbing, one on each cross stub of the fork unit, for two helpers at steps. Each is a 40 mm wide band sewn shut round the stub with a hand loop hanging 130 mm below it, 70 mm across, with a 60 mm foam grip on the bottom of the loop.

**How to make it.**

1. After the fork unit is painted, wrap the webbing round the front stub 100 mm to the left of its centre and sew it shut by hand, tight on the stub.
2. Sew the hand loop below it, and slide the foam tube on before closing the loop.
3. Do the same on the rear stub, 100 mm to the right of its centre, so the two helpers stand on opposite sides of the doli.

**How it fits the parts next to it.**

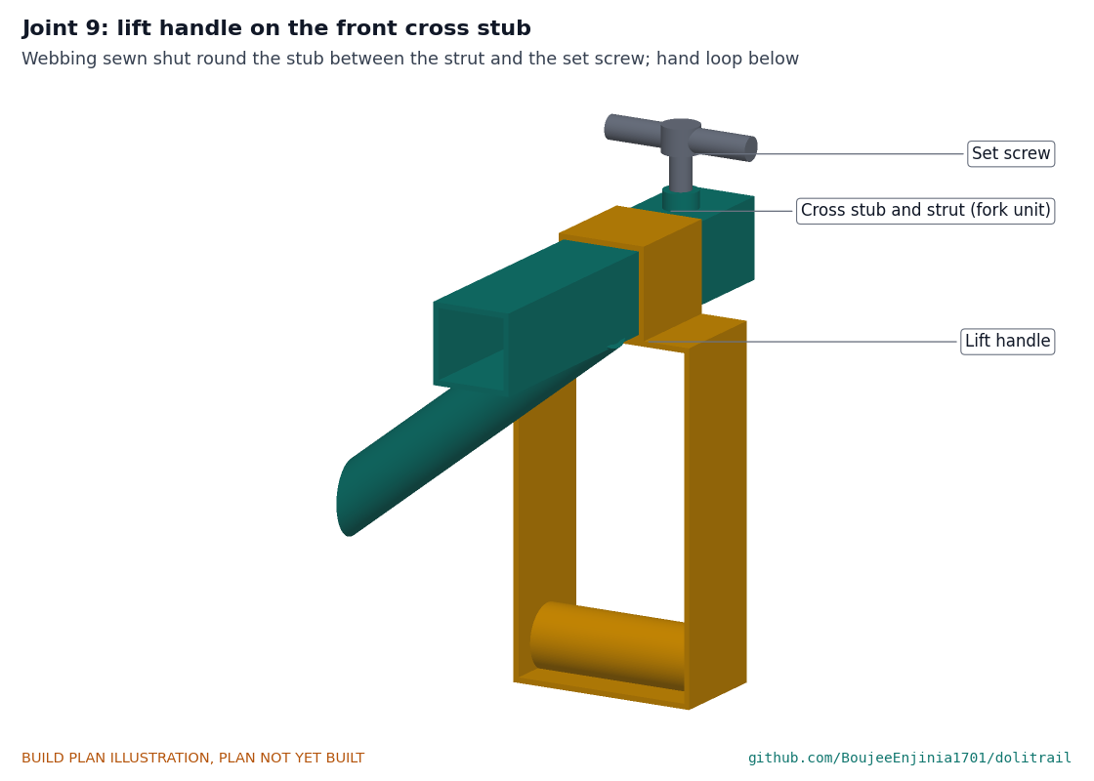
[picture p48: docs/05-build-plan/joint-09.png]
Close-up: lift handle on the front cross stub


*Figure 12. A lift handle on the front cross stub, between the strut and the set screw.*

The band sits between the strut and the set screw's nut, so it cannot slide into either. The loop hangs 69 mm clear of the tyre, with about 160 mm of room for a hand under the pole and the bed. The handles stay on the fork unit and travel in the wheel bag.

**Check before moving on.** Hang 70 kg from each loop for one minute: no stitch pulls and the band does not slide on the stub.

## 4. Putting it together

Steps 1 to 4 are done once in the workshop; the wheel and the lift handles then stay on the fork unit. Steps 5 to 9 are the fitting to a doli, about five minutes for two people.

### Step 1: fit the rotor and the wheel

Step 1

Bolt the rotor to the hub (left side) to the torque on its packet. Lift the axle up into both slots and tighten the nuts outside the plates with a spanner. Spin the wheel: it runs true and clear of the struts.

### Step 2: bolt the caliper to the lobe

Step 2

Bolt the caliper and adapter to the lobe, centre it on the rotor, set the pads about 0.5 mm off, and run the cable through the housing to the lever (the lever stays loose for now).

### Step 3: slide the side arms into the stubs

Step 3

Slide each arm into its stub end, posts upward and outward. Set the saddles to the doli's pole spacing (measure centre to centre).

### Step 4: lock the set screws

Step 4

Tighten the four set screws by hand. Each spigot must be at least 75 mm inside its stub.

### Step 5: set the frame under the poles, wheel under the hips

Step 5

Two people raise the doli on their knees or on two blocks. Slide the frame under it so the wheel sits under the patient's hips (the belt line), and the saddles sit under both poles at bare pole, sliding any bed lashing about 70 mm aside.

### Step 6: close the four clamps

Step 6

Lay each upper jaw over its pole; run both T-bolts into the nuts in even turns until the rubber just bulges. Hand tight only, never with a bar.

### Step 7: fit the cross strap

Step 7

Pass the strap round both poles just ahead of the wheel's top, under the bed, and pull it tight.

### Step 8: fit the lever mount on the front right pole

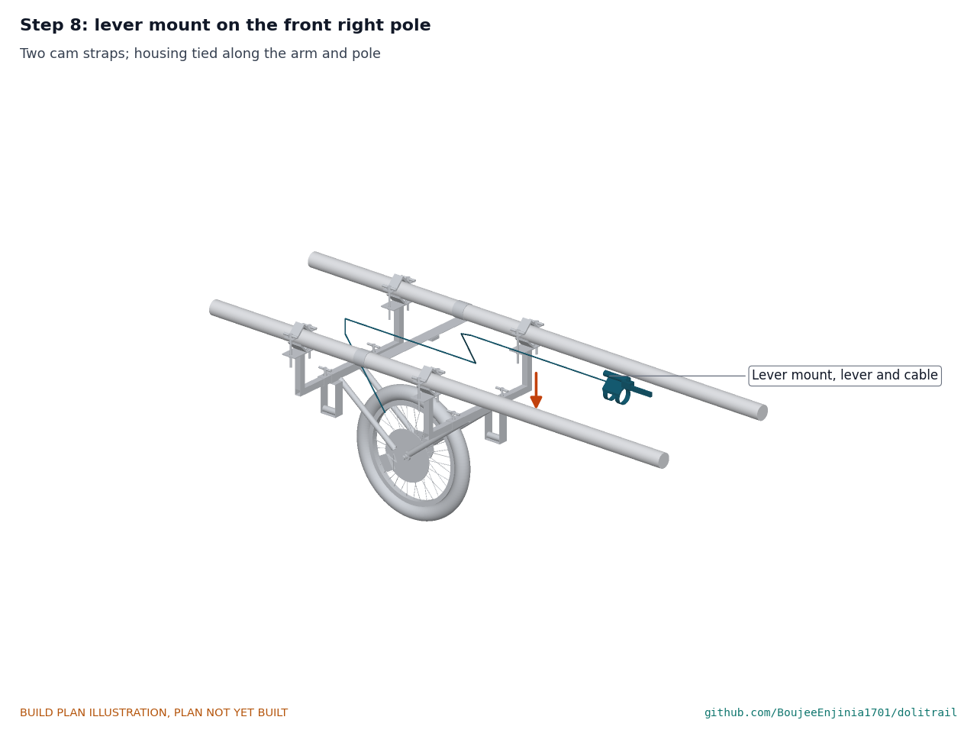
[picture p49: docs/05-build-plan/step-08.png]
Step 8


Strap the mount on top of the front right pole about 150 mm behind where the front bearer's pole loop will sit. Clamp the lever on its bar, blade toward the bearer's hand. Tie the housing along the arm and the pole with the hook-and-loop ties, with no tight bends. Pull the lever: the wheel locks; set the parking lock: it stays locked.

### Step 9: patient straps, harness loops and hold-back strap

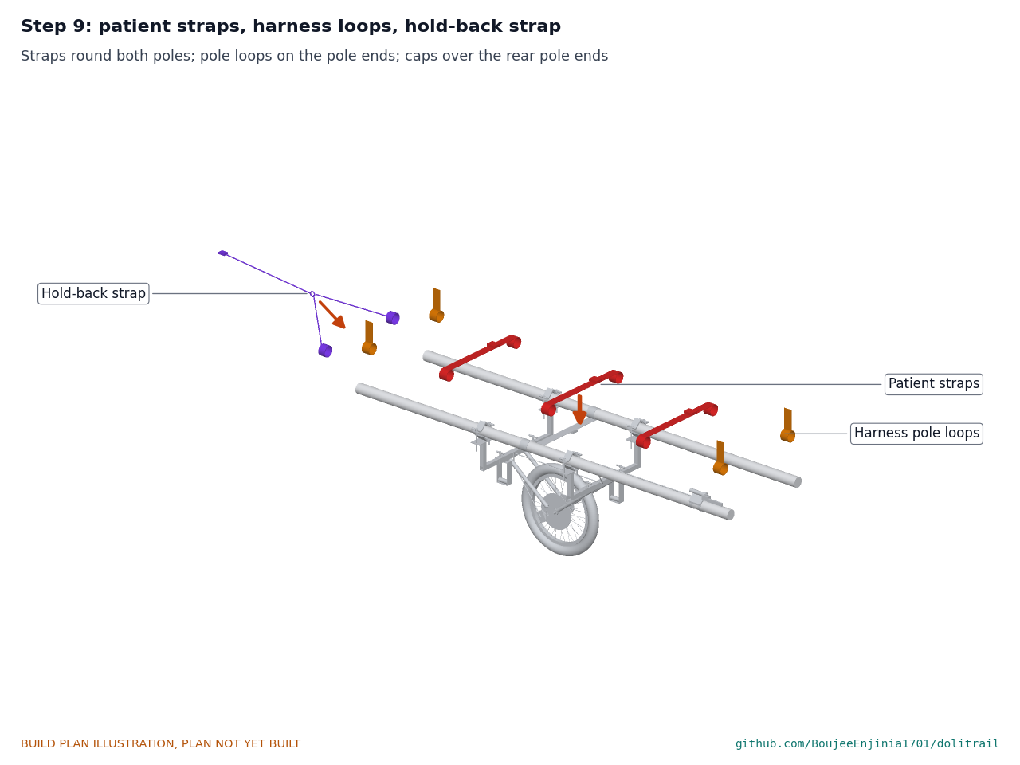
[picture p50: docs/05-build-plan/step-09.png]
Step 9


Pass the three patient straps round both poles at the chest, hips and legs. The bearers put on their harnesses, set the slings to knuckle height and slip the pole loops over the pole ends. Slip the hold-back caps over the rear pole ends behind the rear bearer's pole loops, cinch them, and clip the tail to the rear bearer's hip belt.

## 5. First checks

These are listed here and recorded in a TRL 4 test report. Sandbags stand in for a patient.

*Table 2. First checks.*

| Check | Requirement | How | Pass when |
| --- | --- | --- | --- |
| Clamp range | R1 | Close a clamp on 40, 60 and 80 mm bamboo | Both liners touch; jaw clear of the saddle |
| Clamp slip | R1 | Pull the fitted frame along the poles with CalRig | No slip at 1.5 kN on wet poles |
| Proof load | R3 | 260 kg of sandbags on the fitted doli, wheel on a block, 10 min | No permanent set in the frame, no weld cracks, no clamp movement |
| Wheel proof load | R3 | Every bought wheel, before the kit is used: 285 kg on the wheel alone, tyre at full pressure, 10 min | No spoke, rim or tyre damage; if it fails, fit the heavier 20 inch tricycle wheel and 20 x 2.4 cargo tyre and repeat |
| Fitting time | R2 | Two people with only the fitting card | Under 5 min |
| Bearer load | R4 | Load cells in the slings, level trail | Average load per bearer down by 60 per cent or more |
| Brake hold | R5 | Rated sandbag load on a wet 30 per cent ramp, lever locked | Stays put for 5 min |
| Hold-back strap | R5 | Rated sandbag load on a wet ramp, rear bearer clipped in, pull measured | The bearer holds the doli back standing upright |
| Width | R6 | Measure over the clamps | 700 mm or less on the reference doli |
| Mass | R7 | Weigh each packed bag | Each bag 10 kg or less |
| Step | R8 | 400 mm step, four people: two bearers and two helpers at the lift handles | Over without removing the wheel; recorded load per person about 36 kg |
| Release | R10 | Pull each tab, gloved hand | Free in 3 s |
| Brake reach | R11 | Bearers of 1.5 to 1.8 m | Lever and lock worked without letting go |

## 6. Safety stops

Work stops at each point until what is listed is true.

- **S1, before welding:** jig checked square; fire extinguisher and screens in place.
- **S2, before any load:** every weld inspected by eye for cracks and full fusion; every set screw and T-bolt tight; wheel nuts tight.
- **S3, before the proof loads (frame and every bought wheel):** sandbags only; people stand clear of the doli's sides; the wheel rests on a block.
- **S4, before the wet ramp test:** the proof loads (section 5) have passed; a person holds a safety rope to the rear poles; the ramp has a run-out clear of people.
- **S5, before any trail trial with a person:** the ramp test has passed, the bearers have practised with sandbags, and the partner's crew agree. The first person carried is a healthy volunteer, not a patient. Bearers keep both hands on the poles and never roll through moving water. On every wet descent the rear bearer is clipped to the hold-back strap; on wet clay steeper than 20 per cent the bearers lift and carry. At steps of more than about 250 mm four people lift, two of them at the lift handles; two bearers never lift the fitted doli over a step alone.
- **S6, every fitting:** clamps checked by shaking the doli; poles checked for splits at the clamp points; brake pulled and the lock tried before anyone is strapped on.

## 7. Tools, skills and workspace

- Workshop: a welder (stick or MIG) and a competent welder; angle grinder with cutting and grinding discs; drill press or hand drill with 9 mm bit; bench vice and a 90 deg bending former; files; a flat bench for the jig.
- Tailor: a heavy sewing machine for webbing, UV-resistant thread, a hot knife for sealing.
- Bicycle mechanic: spoke key, 15 mm spanner, Torx or hex keys for the rotor and caliper, cable cutters.
- Fitting: no tools beyond the kit; the T-handles are turned by hand.
- Space: a covered workshop for the steel; a level yard and a test ramp for the checks.

## 8. Where the numbers come from

- Model: `cad/src/model.py` (sizes, constructability checks), `cad/step/` and `cad/stl/`.
- Drawings: `cad/drawings/DLT-DWG-001` (general arrangement) and `DLT-DWG-101` to `108` (making sketches).
- Calculations: `docs/04-calcs/01-sizing.md` (DLT-CAL-001), `docs/04-calcs/sizing.py`, `docs/04-calcs/results.csv`.
- Bill of materials: `bom/bom.csv`.
- Pictures: `cad/src/build_plan_media.py`.

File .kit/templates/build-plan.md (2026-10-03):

---
doc_id: PRJ-BLD-001
title: Project prototype build plan
project: Project name
doc_type: Build plan
version: "0.1"
status: Draft
date: YYYY-MM-DD
author: Amish Chadha
license: CERN-OHL-S-2.0
revisions:
  - version: "0.1"
    date: YYYY-MM-DD
    author: Amish Chadha
    change: First build plan; design made constructable
---

# Project prototype build plan

**Plan, not yet built.** How to build the first proof-of-concept prototype, component by component. Building and testing to it is TRL 4 work. Decisions still to be made are kept in the design decisions register (`docs/06-design-decisions.md`), not here.

## 1. What you are building

Every component, pulled apart and numbered in build order

One short paragraph: what the prototype is, how many components, which are made and which are bought, and the main ways they are made.

## 2. What changed to make it buildable

| Component | The concept had | The buildable design has | Why |
| --- | --- | --- | --- |

## 3. Making the components

### 3.1 Component name

Making sketch

**What it is and what it is made from.**

**How to make it.**

1. Mark out ...
2. Cut ...

**How it fits the parts next to it.**

Close-up of the joint

**Check before moving on.**

## 4. Putting it together

### Step 1: ...

Step 1

## 5. First checks

| Check | Requirement | How | Pass when |
| --- | --- | --- | --- |

## 6. Safety stops

## 7. Tools, skills and workspace

## 8. Where the numbers come from

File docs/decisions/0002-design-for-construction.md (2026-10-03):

---
doc_id: DLT-DDR-002
title: DoliTrail design for construction
project: DoliTrail
doc_type: Design decision record
version: "0.1"
status: Draft
date: '2026-10-03'
author: Amish Chadha
license: CERN-OHL-S-2.0
revisions:
- version: "0.1"
  date: '2026-10-03'
  author: Amish Chadha
  change: Design made constructable; changes C1 to C11 and assumptions A1 to A5 decided under Amish's 2026-10-03 pre-approvals
---

# 0002: Design for construction

- **Date:** 2026-10-03
- **Status:** decided. Decided by Amish under his pre-approval of 2026-10-03: "start with the first 14 repos from the list of 29 projects. I pre-approve the batch runs along with any recommendations you come up with. I also accept any cost overruns or variations from the assumed scope cost." and his instruction of the same day: "Proceed with the remaining 15 scaffolds".

## Context

STANDARDS section 18 asks that every part can be made by a stated process and fits and fastens to its neighbours. The concept named a "wheel and fork", "pole clamps", a "cross frame and strap", a "brake and lever" and "pole-end cups", but did not say how the fork reaches the poles past a sagging bed, how the clamps adjust, where the brake caliper mounts or how the lever fixes to bamboo. The constructability review of the model (`cad/src/model.py`, 75 checks: overlaps and contacts between every part, the wheel in the fork with mud clearance, the caliper on its lobe, the arms in the stubs, the liners on the pole, the clamp closing on 40 and 80 mm poles, bolts clear of the pole, strap and bed clearance over the tyre, ground clearance, width) led to the changes below. None changes what the product does or its pitch.

## Changes

*Table 1. Changes made for construction.*

| # | The concept had | The constructable design has | Why |
| --- | --- | --- | --- |
| C1 | "A single wheel in a fork under the middle" | A welded fork unit: two 30 x 30 x 2 mm square cross stubs 600 mm apart, four 22.2 x 1.6 mm struts, 5 mm dropout plates with slots open downward | The stubs sit fore and aft of the 514 mm wheel, below the bed; the struts carry the load and the braking force as a truss |
| C2 | "Pole clamps" for varied diameters | Four side arms: a 25 mm square spigot sliding in a stub, a post and a 90 deg V saddle; upper jaw of bent 3 mm strip; 5 mm rubber liners | The V centres any pole of 40 to 80 mm; the arms telescope for 450 to 600 mm pole centres |
| C3 | Clamp tightening not stated | Two M8 T-handle bolts per clamp into nuts welded under the saddle; M8 T-handle set screws lock the arms | Hand tight, no loose tools (R1, R2) |
| C4 | "Cross frame and strap" | Frame is the fork unit and arms; the strap is a 50 mm webbing loop round both poles above the wheel | Keeps the bed 174 mm above the tyre; the frame alone is rigid |
| C5 | "Cable or rod brake" | 203 mm disc rotor on the hub; cable caliper on a lobe of the left dropout plate | Mount welded into the plate; the caliper sits low at the rear, clear of struts and spokes |
| C6 | "Lever at the front bearer's hand" | Lever mount: a 22.2 mm bar stub on a rubber-lined inverted V, two cam straps round the front right pole | A bicycle lever needs a 22.2 mm bar; bamboo poles vary |
| C7 | "Pole-end cups" | Pole loops on adjustable slings (D4) | Fits every pole end |
| C8 | Wheel fixing not stated | Solid 3/8 inch axle and nuts in slots open downward | Nothing to open by mistake; the wheel stays in the fork for carrying |
| C9 | Bed and clamp clash not considered | Clamps go on bare pole: where the bed is lashed or tied, the lashing is slid aside about 70 mm at each clamp point | The inboard bolt passes beside the pole where a bed covering leaves it |
| C10 | Carry bag | Wheel bag taking the fork unit with the wheel fitted | Protects the spokes; saves fitting time |
| C11 | No maintenance items | Pump and puncture kit; hook-and-loop ties for the brake housing | A flat tyre on the trail ends the use of the kit |

## Assumptions decided with the changes

- **A1.** The doli's poles are sound bamboo of 40 to 80 mm with no splits at the clamp points; a split pole is not used. Relaxed only by crush tests on local bamboo.
- **A2.** Clamp force is set by hand on the T-handles to about 1 kN per bolt (rubber just bulging); never with a bar or spanner, so the bamboo is not crushed.
- **A3.** The bed covering can be moved aside at the clamp points. If a covering is sewn round the poles as a sleeve, the kit is not fitted to that doli until the partner trial decides how (DLT-DEC-001, item to confirm).
- **A4.** Wheel, tyre and brake ratings are confirmed when bought (DLT-DEC-001).
- **A5.** Welds by a competent welder, inspected visually; fork unit welded in a jig with a 100 mm spacer bar in the dropouts.

## Consequences

- The kit has 15 BOM lines; six are made (fork unit, side arms, jaws, liners, lever mount, harnesses), the rest bought.
- The general arrangement DLT-DWG-001 is at Rev P2; making sketches DLT-DWG-101 to 106; build plan DLT-BLD-001.
- `design_state: constructable` in `project.yaml`.

> **Safety:** The frame carries a person. Every weld is inspected, the frame and clamps are proof-loaded to twice the rated load, and the brake is tested on a wet ramp with a dummy load before any patient is carried (DLT-BLD-001, sections 5 and 6).

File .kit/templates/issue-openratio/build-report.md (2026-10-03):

---
name: Build report
about: Tell us what happened when you built, printed or tested part of this design
title: "Build report: "
labels: build-report
---

This is a research and educational prototype, not a medical device. It is a TRL 3 concept and is not released for fabrication. If you build any part of it, you do so at your own risk. Reports help everyone.

**What you built** (part, sub-assembly or test)

**Materials, tools and settings**

**What worked**

**What did not work, with photos or measurements if you have them**

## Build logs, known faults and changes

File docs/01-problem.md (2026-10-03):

---
doc_id: DLT-PRB-001
title: DoliTrail problem statement
project: DoliTrail
doc_type: Problem statement
version: "0.2"
status: Draft
date: '2026-10-03'
author: Amish Chadha
license: CERN-OHL-S-2.0
revisions:
- version: "0.1"
  date: '2026-09-30'
  author: Amish Chadha
  change: Initial scaffold
- version: "0.2"
  date: '2026-10-03'
  author: Amish Chadha
  change: TRL 2 and 3 update; constraints worded as a value-engineering target, open questions settled (DLT-DDR-001), first co-design candidates, safety section
---

# DoliTrail problem statement

Where roads end, patients are carried, and the only equipment is a stretcher and the bearers' shoulders.

## The problem

Reports from Odisha, Madhya Pradesh, Meghalaya, Chhattisgarh and Jammu and Kashmir describe carries of 3 to 8 km on stretchers made from bamboo and cloth or on ambulance stretchers, over mud, snow, streams and forest trails ([ANI, 2026](https://aninews.in/news/national/general-news/pregnant-woman-carried-7-km-on-stretcher-due-to-no-road-connectivity-in-odishas-mayurbhanj20260823102717/); [The Tribune, 2021](https://www.tribuneindia.com/news/nation/madhya-pradesh-no-motorable-road-relatives-carry-pregnant-woman-on-makeshift-stretcher-for-8-km-287707); [The Tribune, 2022](https://www.tribuneindia.com/news/nation/pregnant-meghalaya-woman-taken-to-hospital-on-bamboo-stretcher-for-5-km-429099); [Gulf News, 2020](https://gulfnews.com/world/asia/india/india-video-of-a-pregnant-woman-who-was-taken-to-hospital-on-a-handmade-stretcher-has-gone-viral-1.1594298702634)). In Meghalaya, volunteers took turns to carry ([The Tribune, 2022](https://www.tribuneindia.com/news/nation/pregnant-meghalaya-woman-taken-to-hospital-on-bamboo-stretcher-for-5-km-429099)). Roads will come, as officials promise in these reports, but patients need to move now.

Wheeled litters exist for mountain rescue teams, and the preliminary IP screen found a litter wheel sold without a listed brake and an expired stretcher brake patent, but these fit purpose-built metal rescue litters, not a bamboo doli, and they cost more than a village can spend. The gap is a low-cost, clamp-on wheel with a brake and a harness that fits the stretcher a family has already built.

## Users and context

| User | Need | Context |
| --- | --- | --- |
| Family and neighbour bearers | Carry a patient further with less load on the shoulders and control on descents | Forest and hill trails of 3 to 8 km to the nearest road |
| Ambulance crews (108 and similar services) | A kit they can carry in the vehicle and fit on arrival at the road end | Calls to villages without motorable roads |
| Community health workers and village health committees | A ready kit kept in the village, simple to fit and maintain | Maternal care and emergencies |
| The patient | A steadier, safer ride with less jolting and less risk of being dropped | Women in labour, the injured and the elderly |

## Operating environment

- Narrow forest and hill trails, often under 1 m (3 ft) wide, with steps, roots, rocks and grades of 20 per cent or more (estimate).
- Monsoon mud, stream and river crossings, and snow in some regions.
- Carries of 3 to 8 km, by day or night.
- Dolis built from bamboo poles of varied diameter, with cloth, rope or a cot frame.

## Constraints

- Value-engineering target of USD 1,500 for the parts of one kit (a hypothetical control target, not a spending limit; STANDARDS section 18).
- Must clamp to bamboo poles of about 40 to 80 mm (1.6 to 3.1 in) diameter (estimate) without tools, or with one simple tool.
- Kit mass at or below 10 kg (22 lb) (target) so one person can carry it to the village (R7).
- Clamps fit on bare pole: where the bed is lashed or tied, the lashing is slid aside at the four clamp points (DLT-DDR-002).
- Built from bicycle parts, steel tube and webbing that can be sourced and repaired locally; hardware under CERN-OHL-S-2.0.
- Own clamp geometry and colours (see design-arounds).
- Published as an open engineering reference, not as certified medical or rescue equipment.

## Out of scope

- Motorised drive or power assist.
- A new stretcher or litter; DoliTrail adds to the existing doli.
- Medical care during transport.
- River crossings where the doli must be carried or ferried; the kit is lifted clear.

## Prior work

| Prior work | What it does | Gap for these users | Source |
| --- | --- | --- | --- |
| Cloth and bamboo village stretcher | Stretcher made by relatives from cloth and bamboo sticks and carried by hand | All weight on the bearers; no wheel or brake | [link](https://www.tribuneindia.com/news/nation/madhya-pradesh-no-motorable-road-relatives-carry-pregnant-woman-on-makeshift-stretcher-for-8-km-287707) |
| Hand-made dola | Hand-made carrying stretcher used by health workers over monsoon mud | Carried entirely by hand | [link](https://gulfnews.com/world/asia/india/india-video-of-a-pregnant-woman-who-was-taken-to-hospital-on-a-handmade-stretcher-has-gone-viral-1.1594298702634) |
| Ambulance stretcher carried on foot | Ambulance crew carries the vehicle stretcher to and from the village | Not made for trails; carried entirely by hand | [link](https://aninews.in/news/national/general-news/pregnant-woman-carried-7-km-on-stretcher-due-to-no-road-connectivity-in-odishas-mayurbhanj20260823102717/) |
| Army evacuation stretcher | Military evacuation team carries a patient on a stretcher through snow | Depends on a trained team; carried by hand | [link](https://www.tribuneindia.com/news/j-k/watch-army-men-carry-pregnant-woman-to-hospital-amid-heavy-snowfall-in-j-k-359452) |

## Co-design

A district health system or NGO running maternal health or emergency transport in a hill or forest district, together with community health workers who have carried dolis, to test fit on real stretchers and trails and to decide where kits are kept. First candidates to approach, in order (none approached yet, DLT-DDR-001): a district 108 ambulance operator in Mayurbhanj, Odisha, with its road-end crews; a maternal health NGO working with village health committees in the same block; a volunteer mountain rescue group for trail technique and the step and descent rules.

## Open questions, settled

The scaffold's open questions were settled under Amish's pre-approval of 2026-10-03 (DLT-DDR-001):

- **One wheel or two?** One, under the patient's hips. Two wheels would need a track wider than the doli on trails under 1 m wide; one wheel keeps the width to the doli's own (680 mm on the reference doli).
- **How much of a route can roll?** Unknown until trail surveys with the first partner; the calculations assume rolling on level ground and moderate grades and lifting at steps, rocks and water.
- **Where are kits kept?** First trial: in the ambulance, carried in by the crew, so the kit is maintained by a service. Village storage is a TRL 4 question for the partner.
- **Commercial wheeled litter kits.** Purpose-built litter wheels fit metal rescue litters, not bamboo poles, and cost more than the whole value-engineering target; DoliTrail does not compete with them (see Prior work).
- **Does a harness shift load safely?** The harness takes the pole ends in slings at the bearer's knuckle height; slings are adjustable for bearers of different heights. A fit trial with bearers is TRL 4 work.

## Safety

> **Safety:** DoliTrail carries a person who may be in labour, injured or unconscious, on steep and wet ground. It is an open engineering reference, not certified medical or rescue equipment. The main hazards are a runaway on a descent, the doli tipping sideways on its single wheel, a clamp slipping on wet bamboo, and bearers lifting too much at steps. Bearers keep hold of the poles at all times, lift and carry across water and down steps, and no patient is carried before the frame and wheel are proof-loaded (DLT-BLD-001, sections 5 and 6).

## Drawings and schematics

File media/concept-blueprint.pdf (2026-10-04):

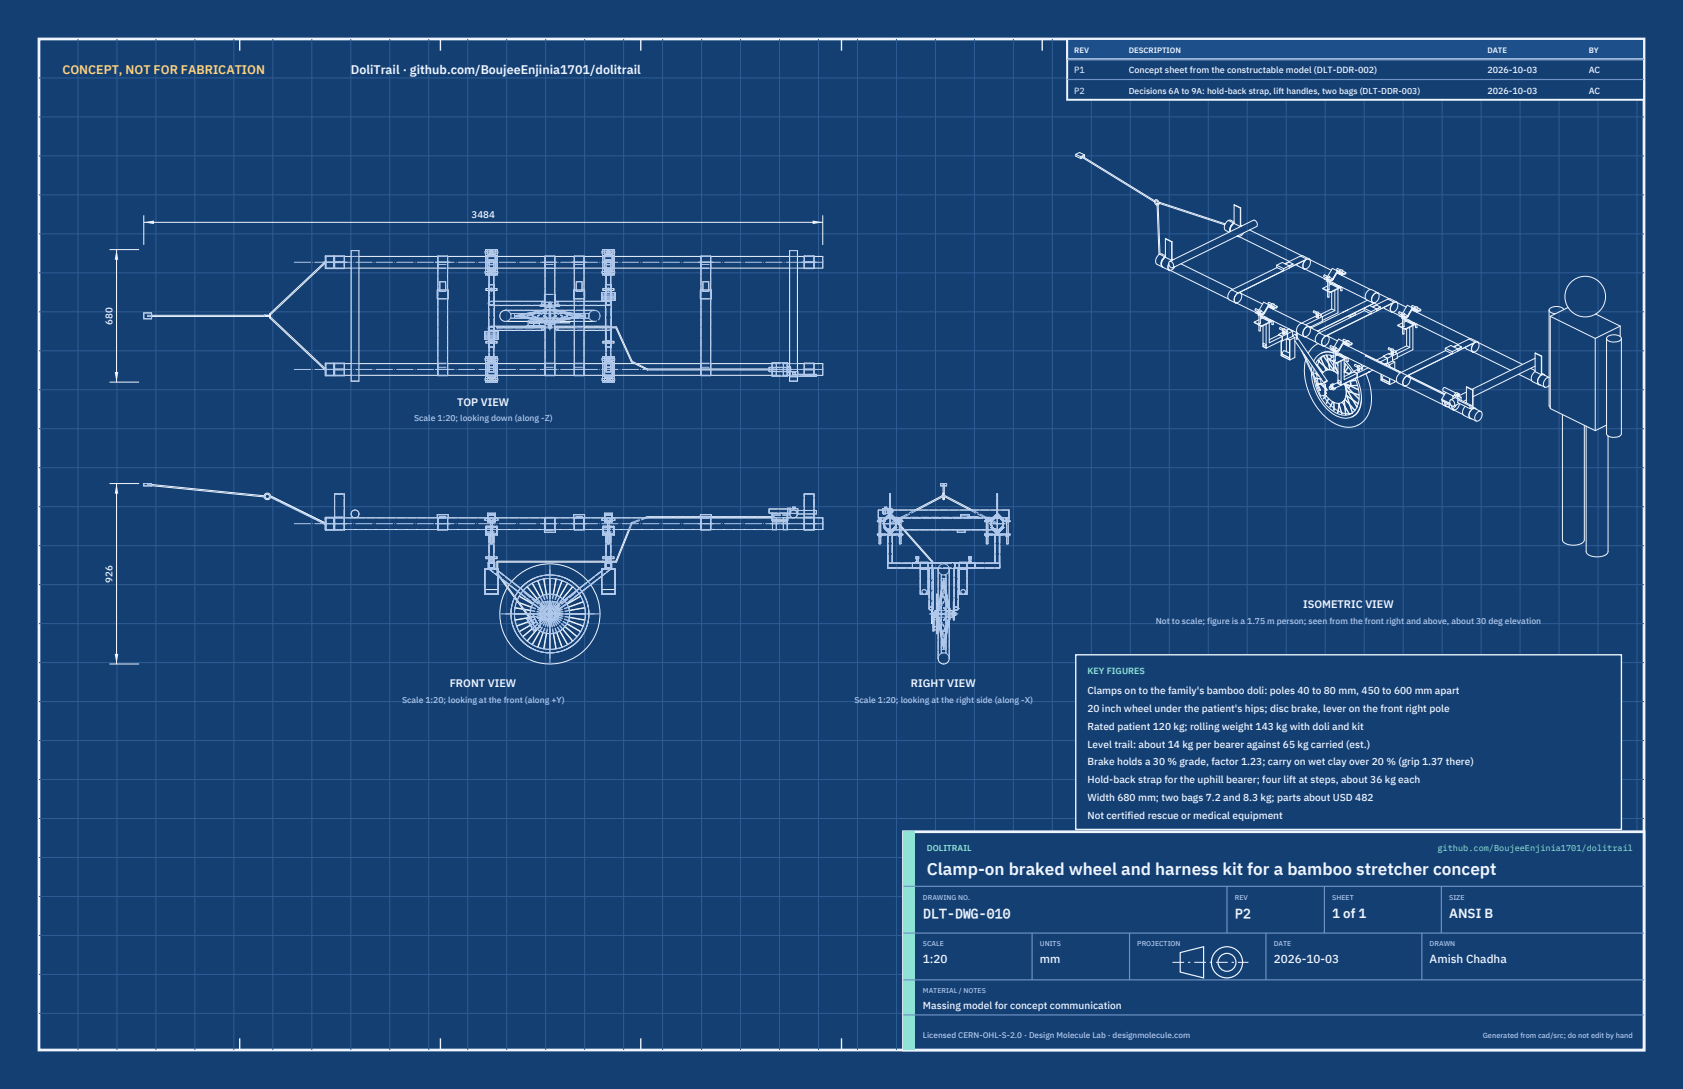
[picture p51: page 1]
CONCEPT, NOT FOR FABRICATION; DoliTrail · github.com/BoujeeEnjinia1701/dolitrail; FRONT VIEW; TOP VIEW; RIGHT VIEW; ISOMETRIC VIEW; REV; DESCRIPTION; DATE; Concept sheet from the constructable model (DLT-DDR-002); Decisions 6A to 9A: hold-back strap, lift handles, two bags (DLT-DDR-003); DOLITRAIL; github.com/BoujeeEnjinia1701/dolitrail; DRAWING NO. DLT-DWG-010; REV P2; SHEET 1 of 1; SIZE ANSI B; SCALE 1:20; UNITS mm; PROJECTION; DRAWN Amish Chadha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

Scale 1:20; looking down (along -Z)

Not to scale; figure is a 1.75 m person; seen from the front right and above, about 30 deg elevation

KEY FIGURES
Clamps on to the family's bamboo doli: poles 40 to 80 mm, 450 to 600 mm apart
20 inch wheel under the patient's hips; disc brake, lever on the front right pole
Rated patient 120 kg; rolling weight 143 kg with doli and kit
Level trail: about 14 kg per bearer against 65 kg carried (est.)
Brake holds a 30 % grade, factor 1.23; carry on wet clay over 20 % (grip 1.37 there)
Hold-back strap for the uphill bearer; four lift at steps, about 36 kg each
Width 680 mm; two bags 7.2 and 8.3 kg; parts about USD 482
Not certified rescue or medical equipment

Scale 1:20; looking at the front (along +Y)

Scale 1:20; looking at the right side (along -X)

Clamp-on braked wheel and harness kit for a bamboo stretcher concept

MATERIAL / NOTES
Massing model for concept communication

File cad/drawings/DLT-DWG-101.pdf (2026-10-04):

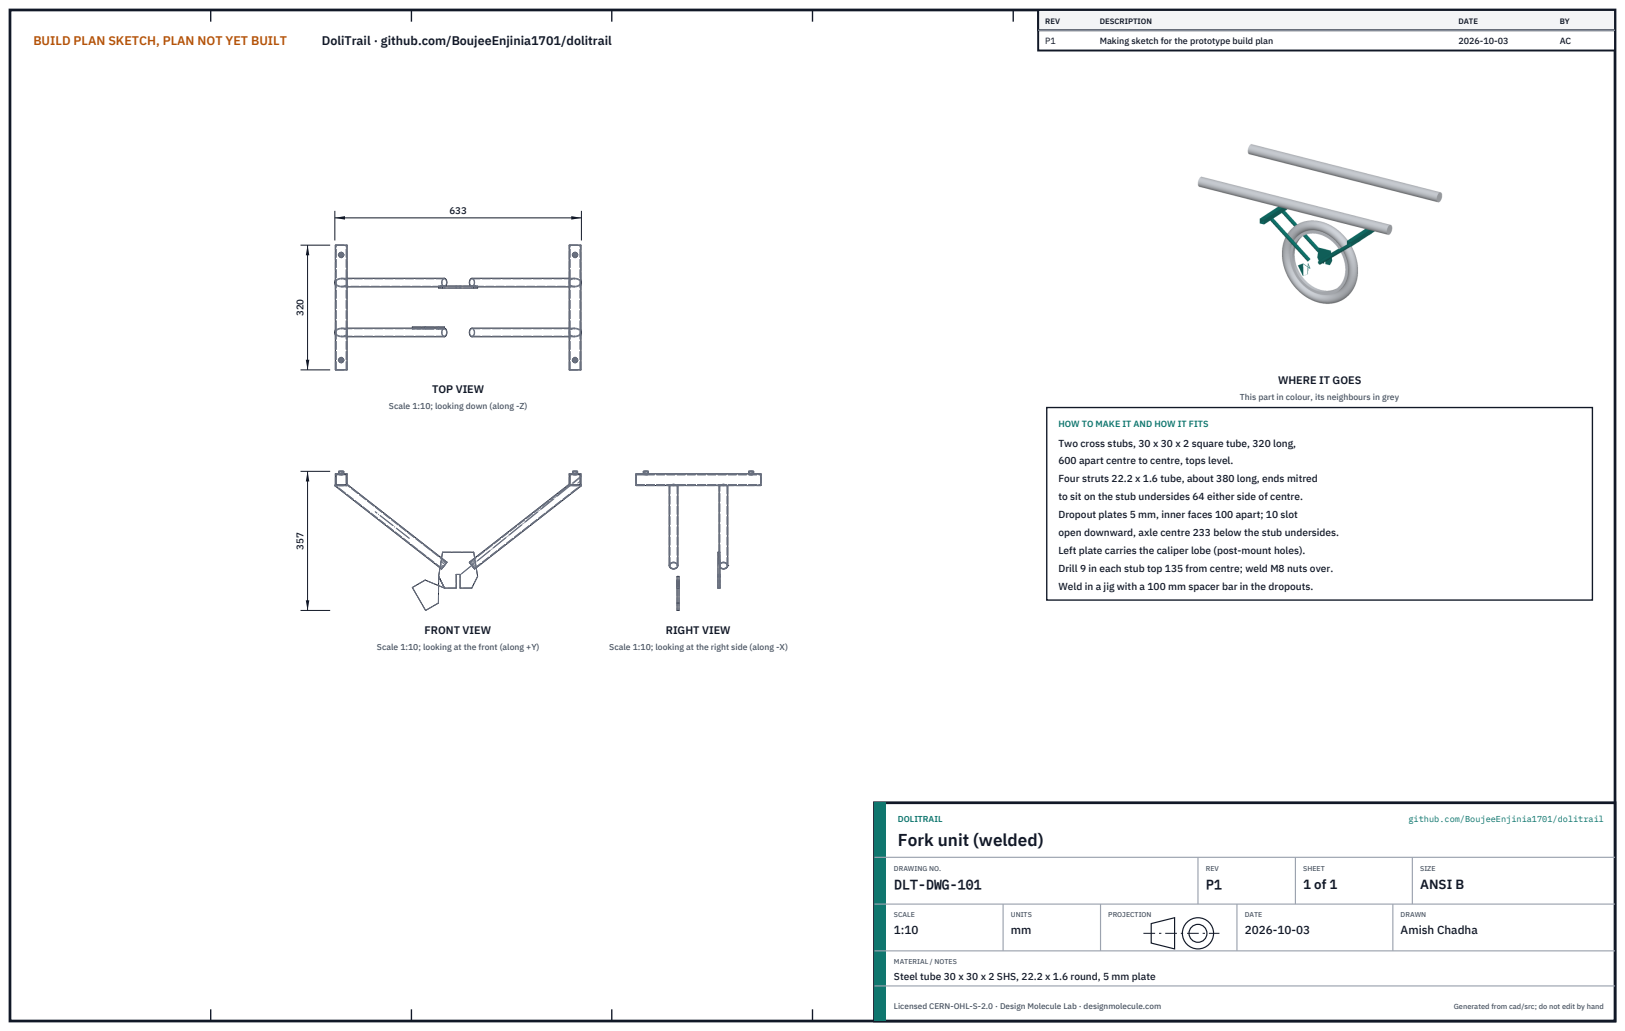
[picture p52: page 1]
BUILD PLAN SKETCH, PLAN NOT YET BUILT; DoliTrail · github.com/BoujeeEnjinia1701/dolitrail; FRONT VIEW; TOP VIEW; RIGHT VIEW; REV; DESCRIPTION; DATE; Making sketch for the prototype build plan; DOLITRAIL; github.com/BoujeeEnjinia1701/dolitrail; DRAWING NO. DLT-DWG-101; REV P1; SHEET 1 of 1; SIZE ANSI B; SCALE 1:10; UNITS mm; PROJECTION; DRAWN Amish Chadha; Licensed CERN-OHL-S-2.0 · Design Molecule Lab · designmolecule.com; Generated from cad/src; do not edit by hand

WHERE IT GOES

This part in colour, its neighbours in grey

Scale 1:10; looking down (along -Z)

HOW TO MAKE IT AND HOW IT FITS
Two cross stubs, 30 x 30 x 2 square tube, 320 long,
600 apart centre to centre, tops level.
Four struts 22.2 x 1.6 tube, about 380 long, ends mitred
to sit on the stub undersides 64 either side of centre.
Dropout plates 5 mm, inner faces 100 apart; 10 slot
open downward, axle centre 233 below the stub undersides.
Left plate carries the caliper lobe (post-mount holes).
Drill 9 in each stub top 135 from centre; weld M8 nuts over.
Weld in a jig with a 100 mm spacer bar in the dropouts.

Scale 1:10; looking at the front (along +Y)

Scale 1:10; looking at the right side (along -X)

Fork unit (welded)

MATERIAL / NOTES
Steel tube 30 x 30 x 2 SHS, 22.2 x 1.6 round, 5 mm plate

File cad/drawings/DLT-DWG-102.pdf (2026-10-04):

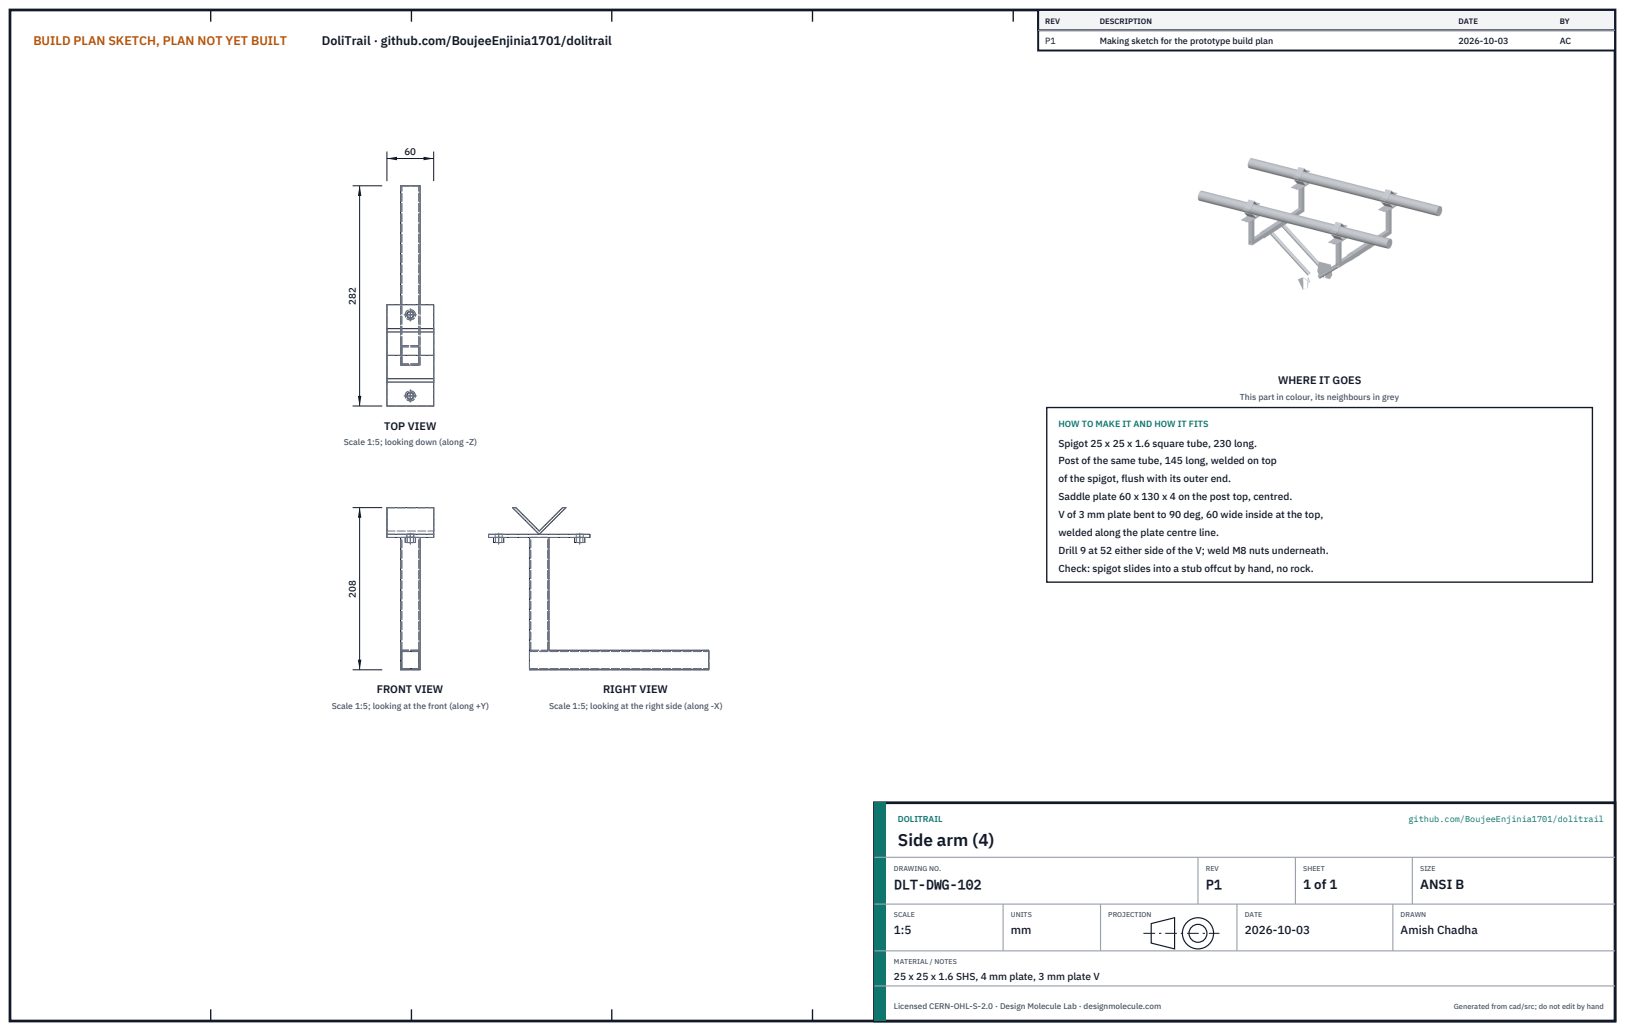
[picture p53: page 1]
BUILD PLAN SKETCH, PLAN NOT YET BUILT; DoliTrail · github.com/BoujeeEnjinia1701/dolitrail; FRONT VIEW; TOP VIEW; RIGHT VIEW; REV; DESCRIPTION; DATE; Making sketch for the prototype build plan; DOLITRAIL; github.com/BoujeeEnjinia1701/dolitrail; Side arm (4); DRAWING NO. DLT-DWG-102; REV P1; SHEET 1 of 1; SIZE ANSI B; SCALE 1:5; UNITS mm; PROJECTION; DRAWN Amish Chadha; Licensed CERN-OHL-S-2.0 · Design Molecule Lab · designmolecule.com; Generated from cad/src; do not edit by hand

WHERE IT GOES

This part in colour, its neighbours in grey

HOW TO MAKE IT AND HOW IT FITS
Spigot 25 x 25 x 1.6 square tube, 230 long.
Post of the same tube, 145 long, welded on top
of the spigot, flush with its outer end.
Saddle plate 60 x 130 x 4 on the post top, centred.
V of 3 mm plate bent to 90 deg, 60 wide inside at the top,
welded along the plate centre line.
Drill 9 at 52 either side of the V; weld M8 nuts underneath.
Check: spigot slides into a stub offcut by hand, no rock.

Scale 1:5; looking down (along -Z)

Scale 1:5; looking at the front (along +Y)

Scale 1:5; looking at the right side (along -X)

MATERIAL / NOTES
25 x 25 x 1.6 SHS, 4 mm plate, 3 mm plate V

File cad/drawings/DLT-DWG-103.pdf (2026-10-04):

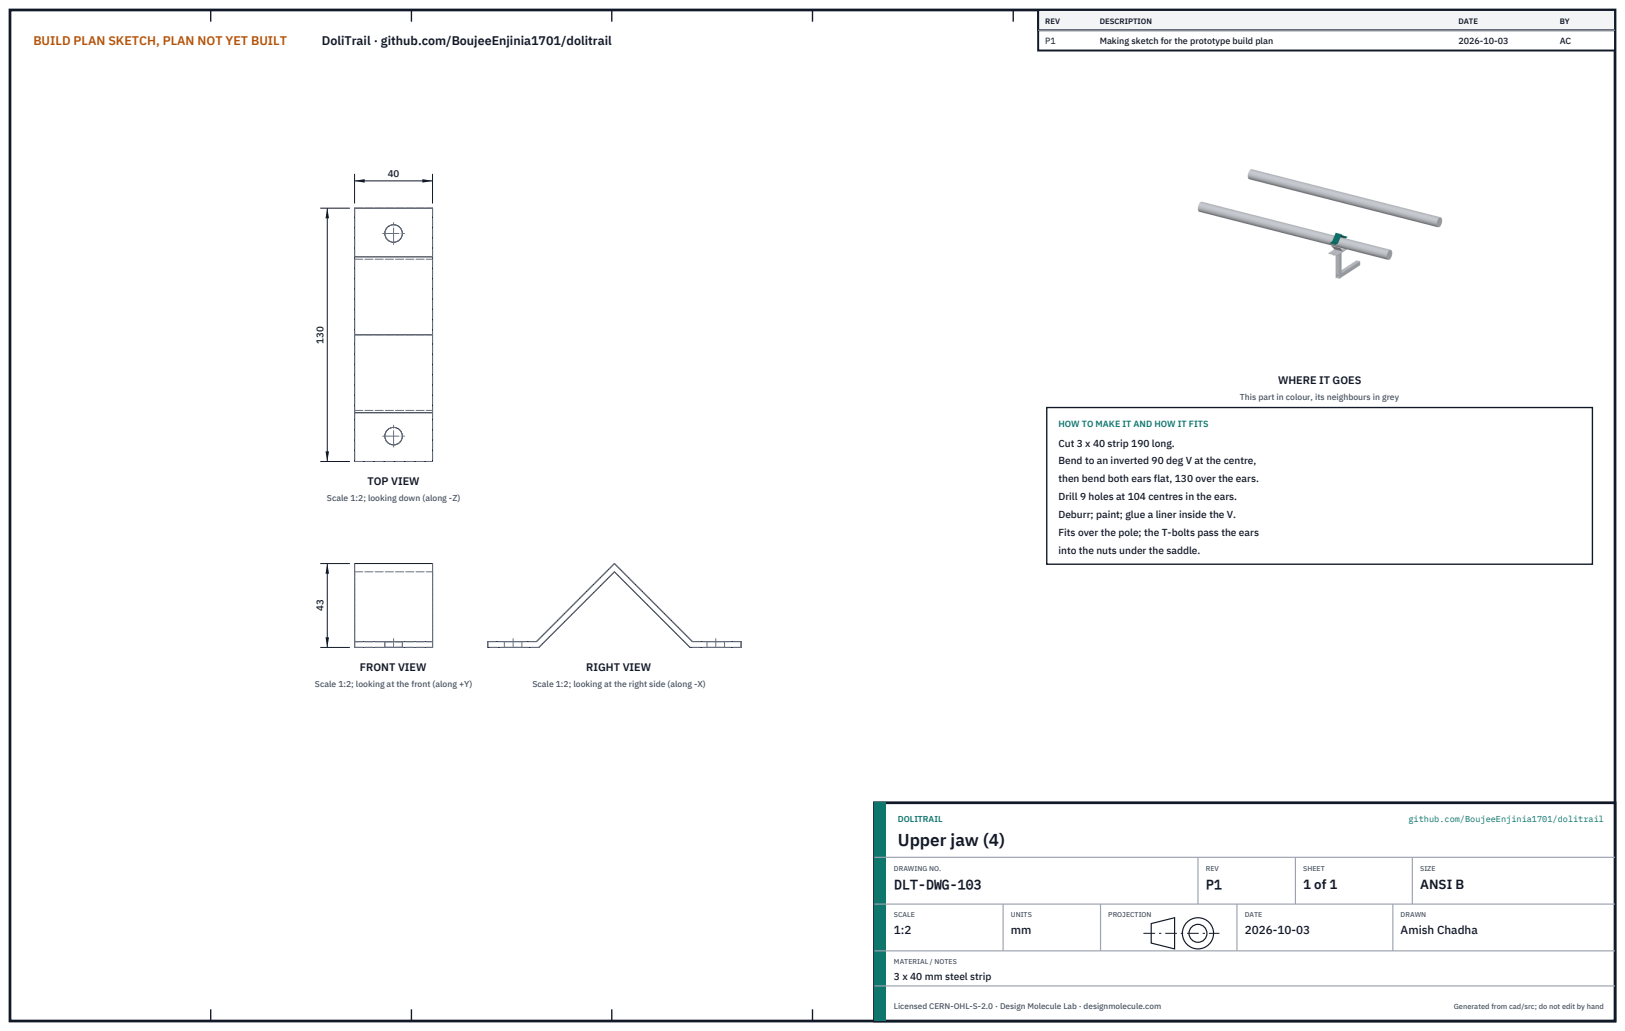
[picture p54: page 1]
BUILD PLAN SKETCH, PLAN NOT YET BUILT; DoliTrail · github.com/BoujeeEnjinia1701/dolitrail; FRONT VIEW; TOP VIEW; RIGHT VIEW; REV; DESCRIPTION; DATE; Making sketch for the prototype build plan; DOLITRAIL; github.com/BoujeeEnjinia1701/dolitrail; Upper jaw (4); DRAWING NO. DLT-DWG-103; REV P1; SHEET 1 of 1; SIZE ANSI B; SCALE 1:2; UNITS mm; PROJECTION; DRAWN Amish Chadha; Licensed CERN-OHL-S-2.0 · Design Molecule Lab · designmolecule.com; Generated from cad/src; do not edit by hand

WHERE IT GOES

This part in colour, its neighbours in grey

HOW TO MAKE IT AND HOW IT FITS
Cut 3 x 40 strip 190 long.
Bend to an inverted 90 deg V at the centre,
then bend both ears flat, 130 over the ears.
Drill 9 holes at 104 centres in the ears.
Deburr; paint; glue a liner inside the V.
Fits over the pole; the T-bolts pass the ears
into the nuts under the saddle.

Scale 1:2; looking down (along -Z)

Scale 1:2; looking at the front (along +Y)

Scale 1:2; looking at the right side (along -X)

MATERIAL / NOTES
3 x 40 mm steel strip

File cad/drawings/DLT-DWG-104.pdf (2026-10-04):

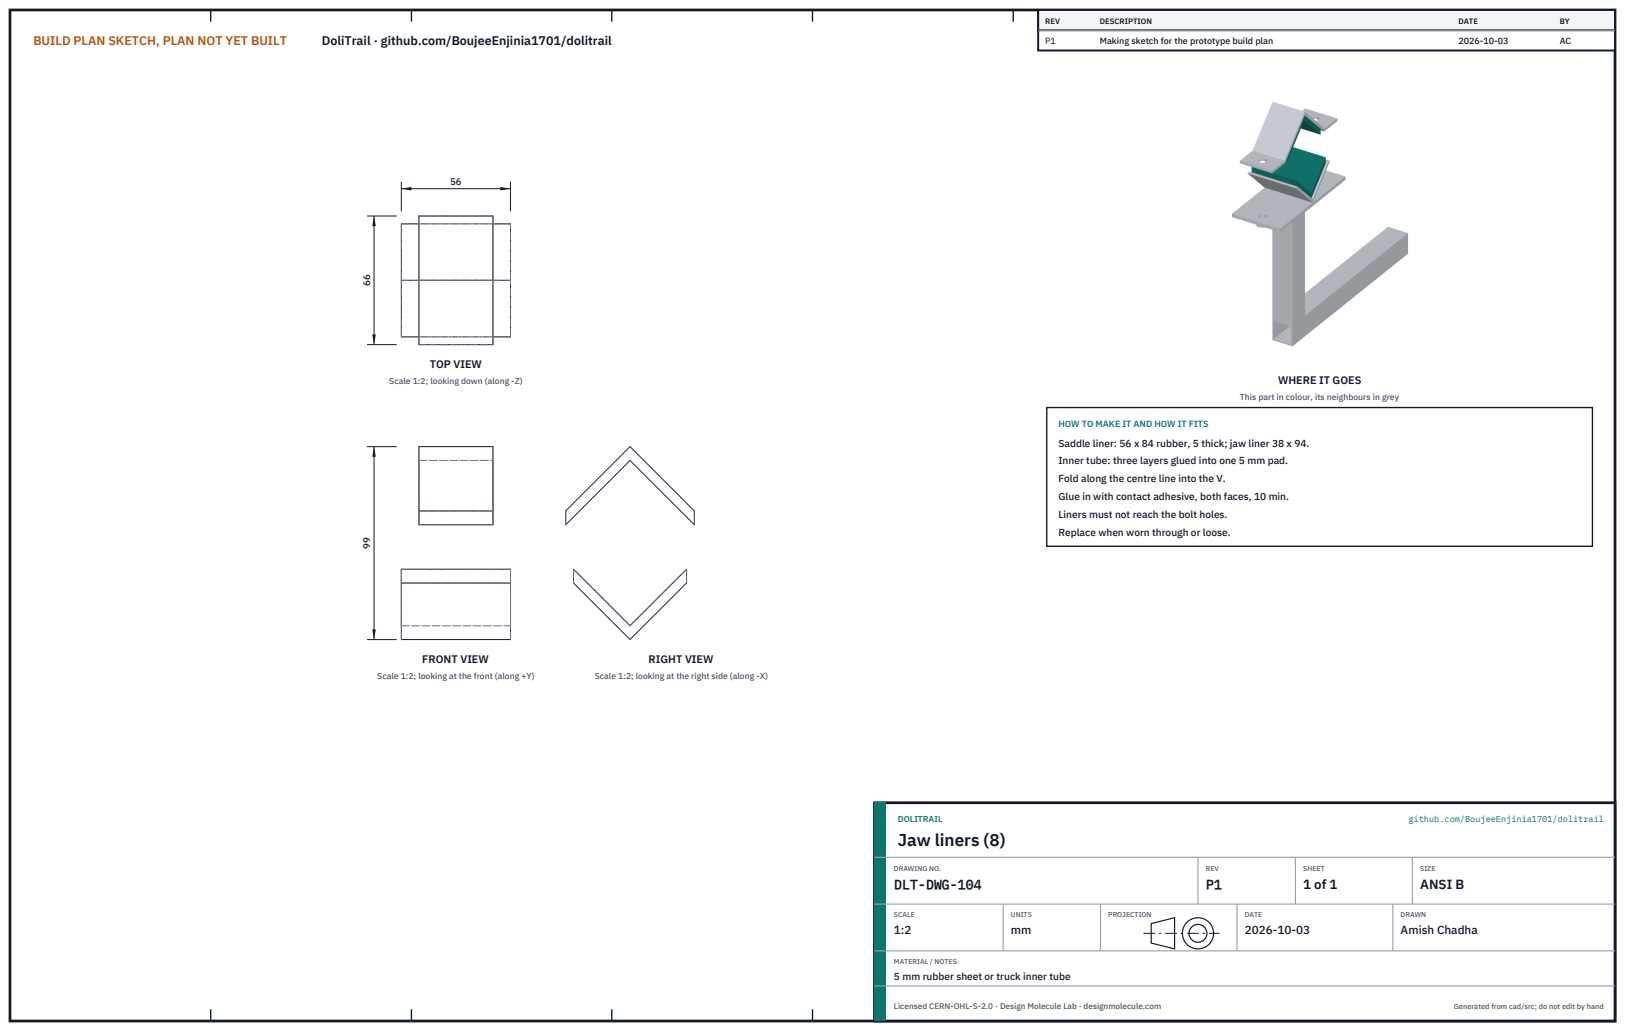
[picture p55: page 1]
BUILD PLAN SKETCH, PLAN NOT YET BUILT; DoliTrail · github.com/BoujeeEnjinia1701/dolitrail; FRONT VIEW; TOP VIEW; RIGHT VIEW; REV; DESCRIPTION; DATE; Making sketch for the prototype build plan; DOLITRAIL; github.com/BoujeeEnjinia1701/dolitrail; Jaw liners (8); DRAWING NO. DLT-DWG-104; REV P1; SHEET 1 of 1; SIZE ANSI B; SCALE 1:2; UNITS mm; PROJECTION; DRAWN Amish Chadha; Licensed CERN-OHL-S-2.0 · Design Molecule Lab · designmolecule.com; Generated from cad/src; do not edit by hand

Scale 1:2; looking down (along -Z)

WHERE IT GOES

This part in colour, its neighbours in grey

HOW TO MAKE IT AND HOW IT FITS
Saddle liner: 56 x 84 rubber, 5 thick; jaw liner 38 x 94.
Inner tube: three layers glued into one 5 mm pad.
Fold along the centre line into the V.
Glue in with contact adhesive, both faces, 10 min.
Liners must not reach the bolt holes.
Replace when worn through or loose.

Scale 1:2; looking at the front (along +Y)

Scale 1:2; looking at the right side (along -X)

MATERIAL / NOTES
5 mm rubber sheet or truck inner tube

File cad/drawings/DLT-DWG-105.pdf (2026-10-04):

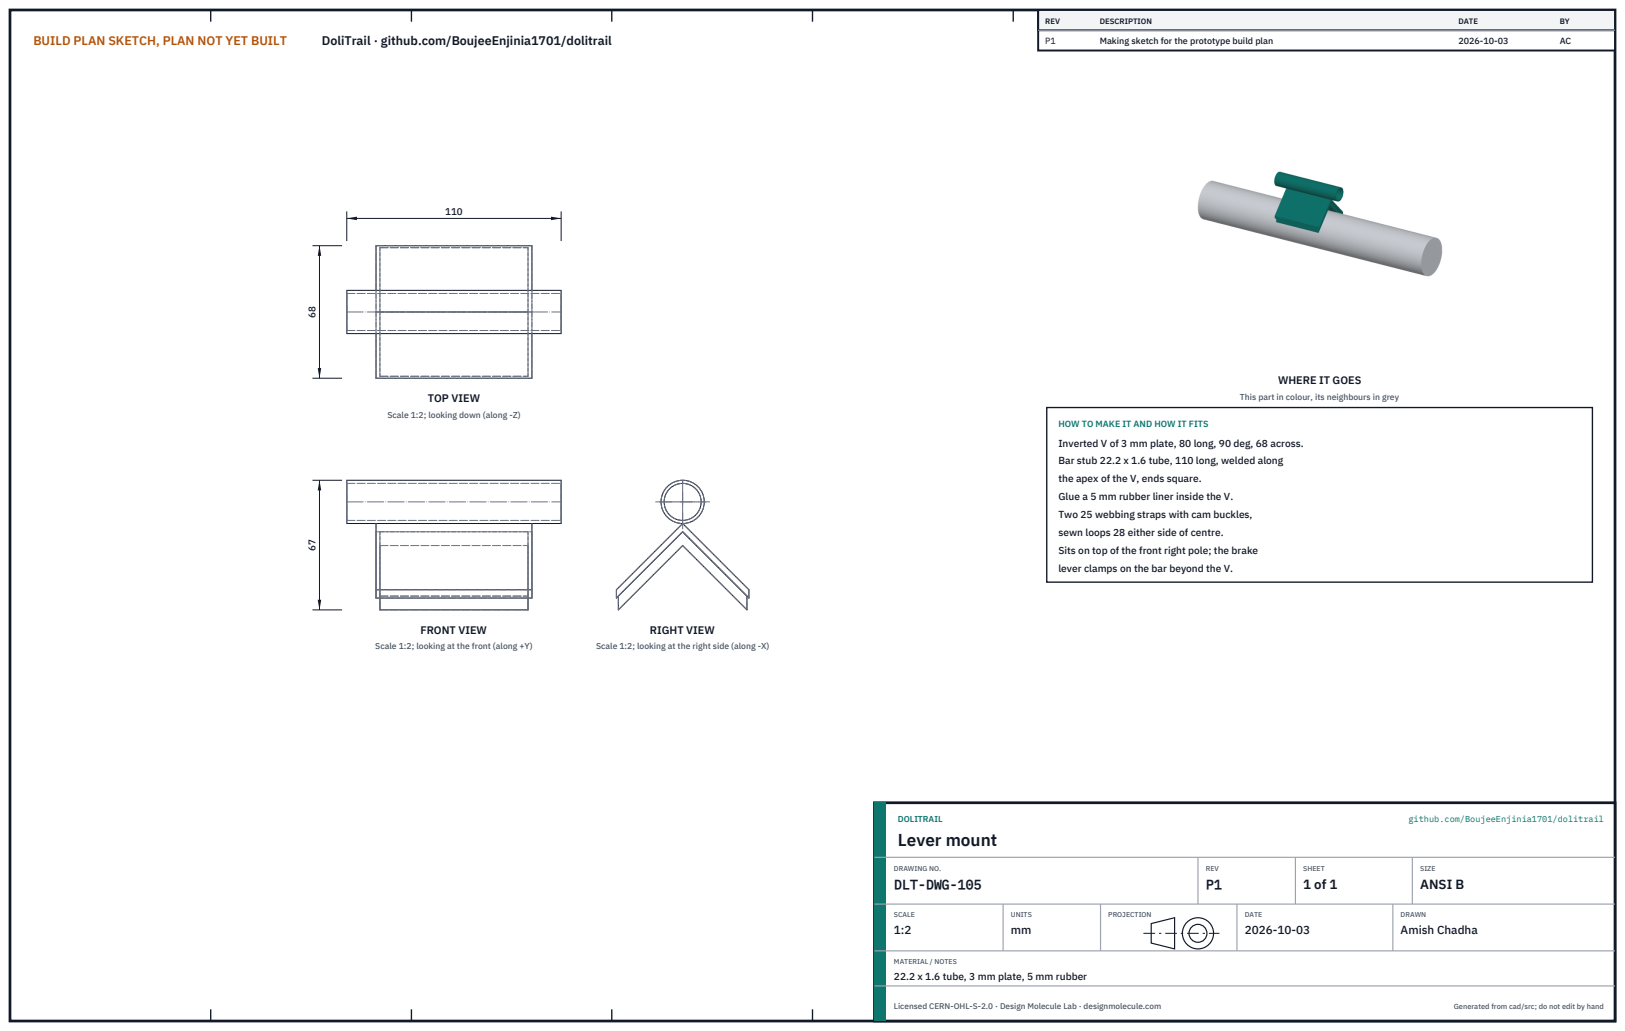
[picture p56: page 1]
BUILD PLAN SKETCH, PLAN NOT YET BUILT; DoliTrail · github.com/BoujeeEnjinia1701/dolitrail; FRONT VIEW; TOP VIEW; RIGHT VIEW; REV; DESCRIPTION; DATE; Making sketch for the prototype build plan; DOLITRAIL; github.com/BoujeeEnjinia1701/dolitrail; Lever mount; DRAWING NO. DLT-DWG-105; REV P1; SHEET 1 of 1; SIZE ANSI B; SCALE 1:2; UNITS mm; PROJECTION; DRAWN Amish Chadha; Licensed CERN-OHL-S-2.0 · Design Molecule Lab · designmolecule.com; Generated from cad/src; do not edit by hand

WHERE IT GOES

This part in colour, its neighbours in grey

Scale 1:2; looking down (along -Z)

HOW TO MAKE IT AND HOW IT FITS
Inverted V of 3 mm plate, 80 long, 90 deg, 68 across.
Bar stub 22.2 x 1.6 tube, 110 long, welded along
the apex of the V, ends square.
Glue a 5 mm rubber liner inside the V.
Two 25 webbing straps with cam buckles,
sewn loops 28 either side of centre.
Sits on top of the front right pole; the brake
lever clamps on the bar beyond the V.

Scale 1:2; looking at the front (along +Y)

Scale 1:2; looking at the right side (along -X)

MATERIAL / NOTES
22.2 x 1.6 tube, 3 mm plate, 5 mm rubber

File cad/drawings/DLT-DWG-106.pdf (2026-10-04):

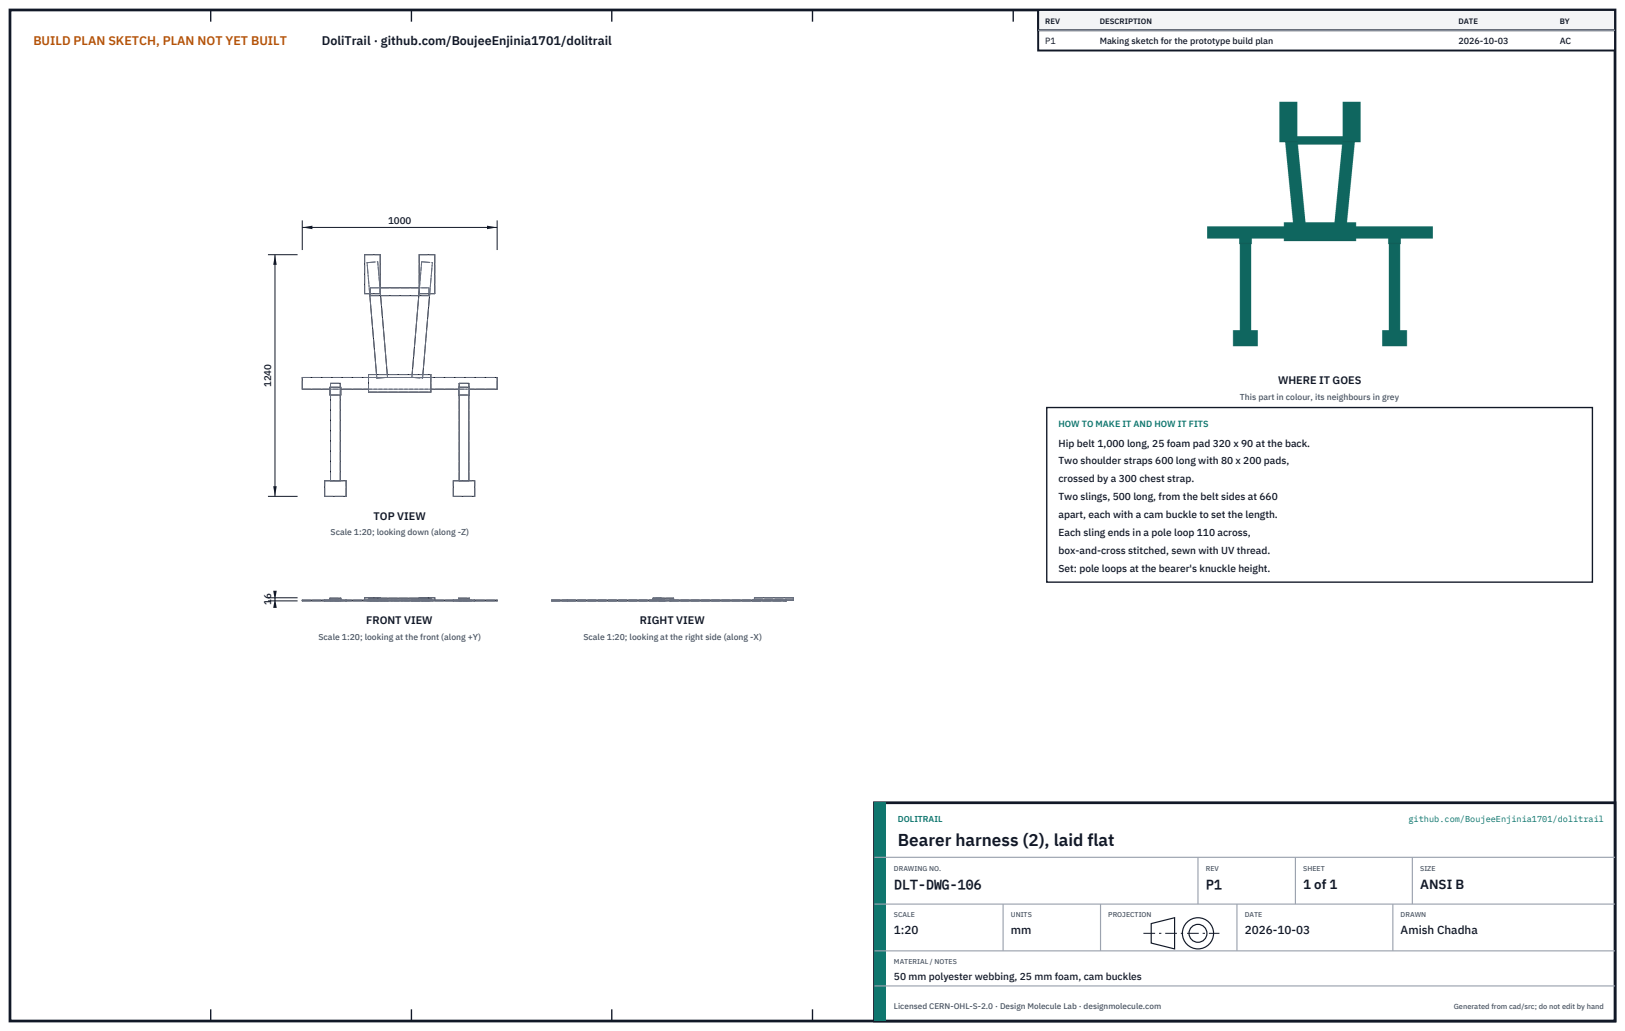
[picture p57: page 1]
BUILD PLAN SKETCH, PLAN NOT YET BUILT; DoliTrail · github.com/BoujeeEnjinia1701/dolitrail; FRONT VIEW; TOP VIEW; RIGHT VIEW; REV; DESCRIPTION; DATE; Making sketch for the prototype build plan; DOLITRAIL; github.com/BoujeeEnjinia1701/dolitrail; DRAWING NO. DLT-DWG-106; REV P1; SHEET 1 of 1; SIZE ANSI B; SCALE 1:20; UNITS mm; PROJECTION; DRAWN Amish Chadha; Licensed CERN-OHL-S-2.0 · Design Molecule Lab · designmolecule.com; Generated from cad/src; do not edit by hand

WHERE IT GOES

This part in colour, its neighbours in grey

HOW TO MAKE IT AND HOW IT FITS
Hip belt 1,000 long, 25 foam pad 320 x 90 at the back.
Two shoulder straps 600 long with 80 x 200 pads,
crossed by a 300 chest strap.
Two slings, 500 long, from the belt sides at 660
apart, each with a cam buckle to set the length.
Each sling ends in a pole loop 110 across,
box-and-cross stitched, sewn with UV thread.
Set: pole loops at the bearer's knuckle height.

Scale 1:20; looking down (along -Z)

Scale 1:20; looking at the front (along +Y)

Scale 1:20; looking at the right side (along -X)

Bearer harness (2), laid flat

MATERIAL / NOTES
50 mm polyester webbing, 25 mm foam, cam buckles

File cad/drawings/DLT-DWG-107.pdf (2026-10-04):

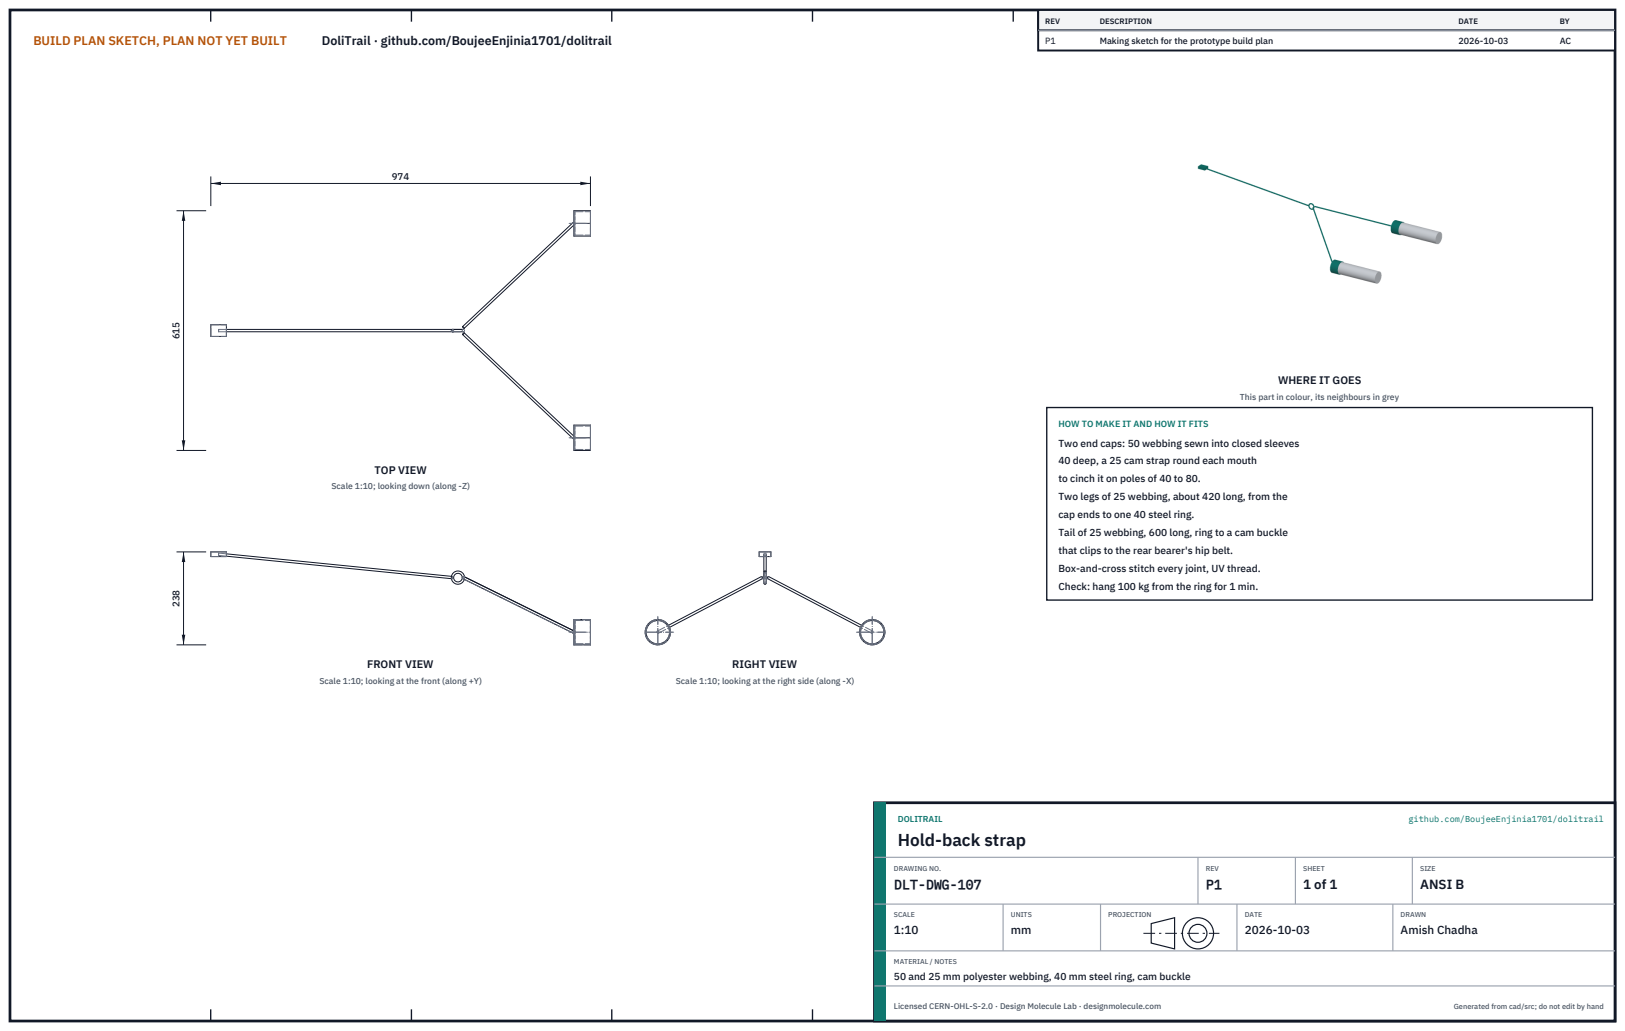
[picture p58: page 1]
BUILD PLAN SKETCH, PLAN NOT YET BUILT; DoliTrail · github.com/BoujeeEnjinia1701/dolitrail; FRONT VIEW; TOP VIEW; RIGHT VIEW; REV; DESCRIPTION; DATE; Making sketch for the prototype build plan; DOLITRAIL; github.com/BoujeeEnjinia1701/dolitrail; DRAWING NO. DLT-DWG-107; REV P1; SHEET 1 of 1; SIZE ANSI B; SCALE 1:10; UNITS mm; PROJECTION; DRAWN Amish Chadha; Licensed CERN-OHL-S-2.0 · Design Molecule Lab · designmolecule.com; Generated from cad/src; do not edit by hand

WHERE IT GOES

This part in colour, its neighbours in grey

HOW TO MAKE IT AND HOW IT FITS
Two end caps: 50 webbing sewn into closed sleeves
40 deep, a 25 cam strap round each mouth
to cinch it on poles of 40 to 80.
Two legs of 25 webbing, about 420 long, from the
cap ends to one 40 steel ring.
Tail of 25 webbing, 600 long, ring to a cam buckle
that clips to the rear bearer's hip belt.
Box-and-cross stitch every joint, UV thread.
Check: hang 100 kg from the ring for 1 min.

Scale 1:10; looking down (along -Z)

Scale 1:10; looking at the front (along +Y)

Scale 1:10; looking at the right side (along -X)

Hold-back strap

MATERIAL / NOTES
50 and 25 mm polyester webbing, 40 mm steel ring, cam buckle

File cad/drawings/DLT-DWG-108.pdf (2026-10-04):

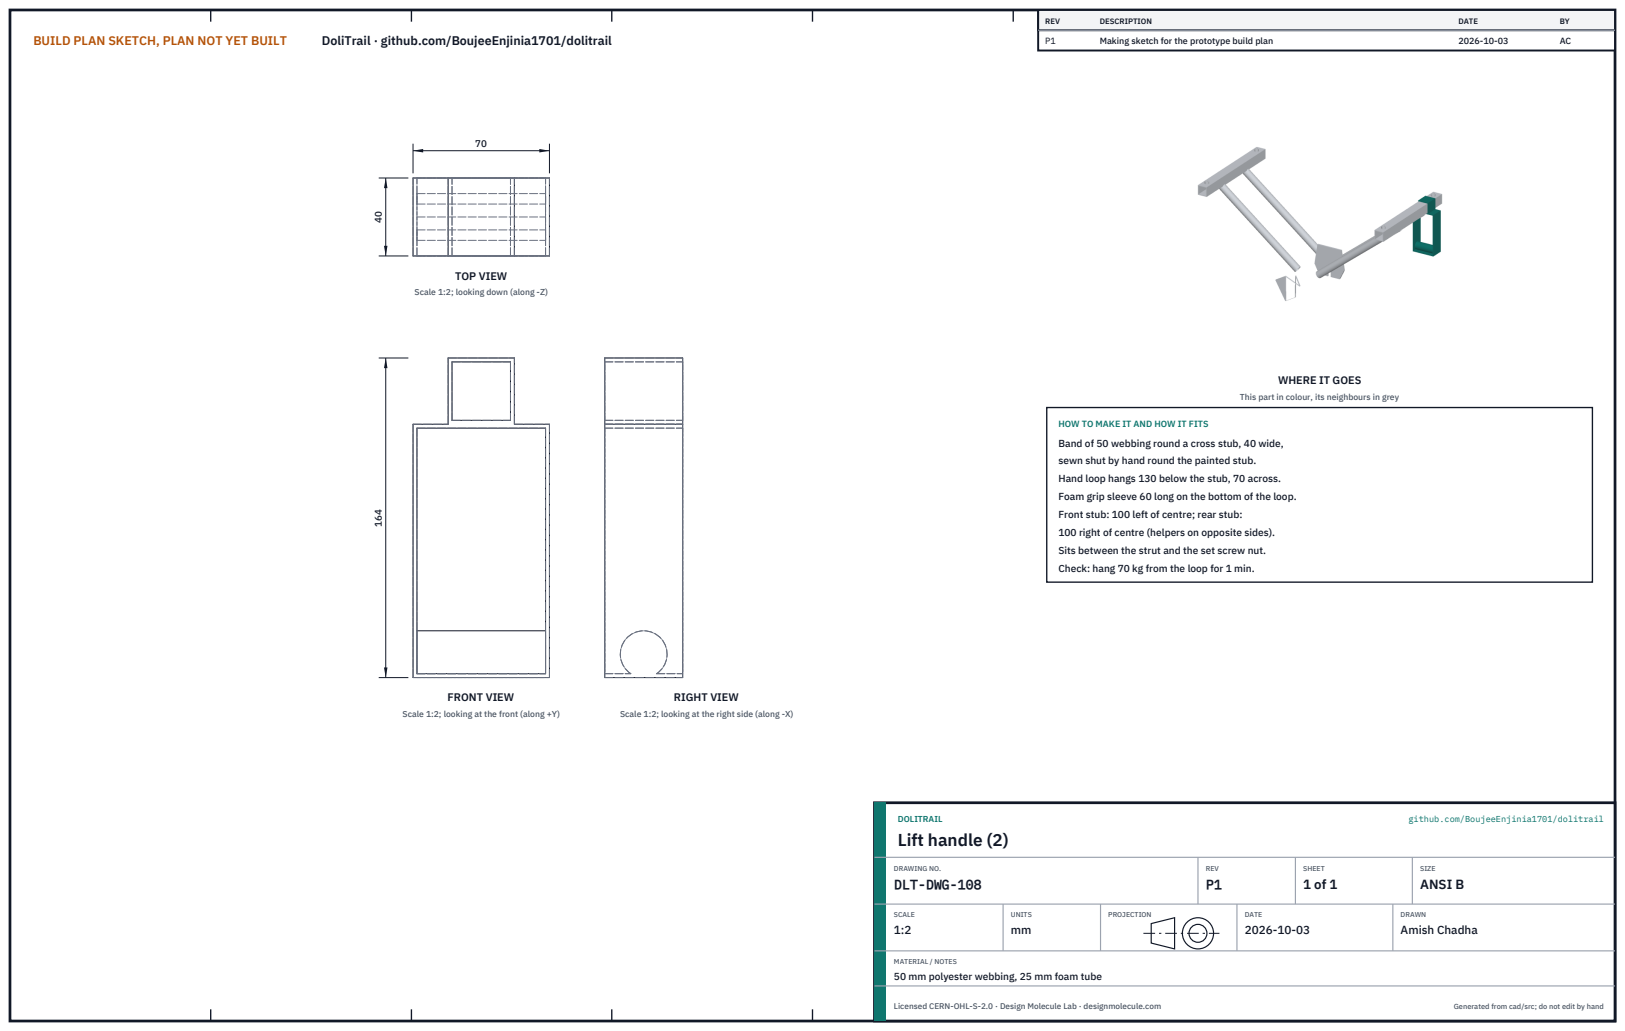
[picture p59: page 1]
BUILD PLAN SKETCH, PLAN NOT YET BUILT; DoliTrail · github.com/BoujeeEnjinia1701/dolitrail; FRONT VIEW; TOP VIEW; RIGHT VIEW; REV; DESCRIPTION; DATE; Making sketch for the prototype build plan; DOLITRAIL; github.com/BoujeeEnjinia1701/dolitrail; Lift handle (2); DRAWING NO. DLT-DWG-108; REV P1; SHEET 1 of 1; SIZE ANSI B; SCALE 1:2; UNITS mm; PROJECTION; DRAWN Amish Chadha; Licensed CERN-OHL-S-2.0 · Design Molecule Lab · designmolecule.com; Generated from cad/src; do not edit by hand

Scale 1:2; looking down (along -Z)

WHERE IT GOES

This part in colour, its neighbours in grey

HOW TO MAKE IT AND HOW IT FITS
Band of 50 webbing round a cross stub, 40 wide,
sewn shut by hand round the painted stub.
Hand loop hangs 130 below the stub, 70 across.
Foam grip sleeve 60 long on the bottom of the loop.
Front stub: 100 left of centre; rear stub:
100 right of centre (helpers on opposite sides).
Sits between the strut and the set screw nut.
Check: hang 70 kg from the loop for 1 min.

Scale 1:2; looking at the front (along +Y)

Scale 1:2; looking at the right side (along -X)

MATERIAL / NOTES
50 mm polyester webbing, 25 mm foam tube

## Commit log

2026-10-03 DoliTrail at TRL 3: constructable design (kit 1.7.0)
    Problem, concept and requirements; sizing calculations; CAD model, STEP and STL; general arrangement drawing; bill of materials; build plan with making sketches, joint close-ups and step pictures; design decisions register (design choices decided under Amish's 2026-10-03 pre-approval; requirement decisions open for Amish); TRL 2 and TRL 3 review; photoreal renders and storefront card. Private until Amish opens it.
    [bom.csv, dolitrail-assembly.step, dolitrail-kit.step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]
2026-10-04 Carry Amish's round 2 requirement decisions into the design
    Amish approved all 47 recommendations on 2026-10-03 ("i approve all of the 47 recommendations provided by you. Execute them."). Each repo gains a decision record (DDR-003, or the next free number for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
    [bom.csv, dolitrail-assembly.step, dolitrail-kit.step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]
2026-10-04 Carry Amish's round-2 and round-3 decisions into the design
    Amish approved all 46 round-2 recommendations ("i agree with all the 46 recommendations you provided. please proceed.") and all round-3 recommendations ("For round 3, I agree with all your proposed r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
    [bom.csv, dolitrail-assembly.step, dolitrail-kit.step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]

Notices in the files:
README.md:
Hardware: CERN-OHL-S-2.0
